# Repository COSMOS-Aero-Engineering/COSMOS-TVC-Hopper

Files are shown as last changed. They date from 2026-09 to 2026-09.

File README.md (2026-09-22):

# COSMOS — TVC 착륙 호퍼 + 강화학습

청도대원학교 항공우주공학 동아리 COSMOS의 26–27학년도 1학기 프로젝트.
단일 EDF 추력 + 배기 베인 4개로 자세를 제어하는 소형 VTOL 호퍼를 만들고,
전통 제어(PID/LQR)와 강화학습(RL) 제어를 정량 비교한다. SpaceX식 재사용 로켓의
역학을 안전한 축소 규모로 재현하는 게 목표.

## 시작점

- **[`AGENTS.md`](AGENTS.md)** — 정본 컨텍스트 문서: 설계 의도·확정 방향·현재 상태·문서 맵·다음 액션·안전 원칙. AI 세션이든 사람이든 기술적인 걸 파악하려면 이거 먼저. (`CLAUDE.md`는 이 파일로 가는 한 줄짜리 안내판)
- **[`docs/design/00-hopper-master-design.md`](docs/design/00-hopper-master-design.md)** — 마스터 설계도 (rev C)
- **[`docs/execution/TIMELINE.md`](docs/execution/TIMELINE.md)** — ⭐ **전체 타임라인 한 장** (간트차트로 한 것/남은 것/현재 병목). 진행 상황이 궁금하면 여기부터
- **[`docs/execution/week-01-kickoff.md`](docs/execution/week-01-kickoff.md)** — 1–2주차 실행 계획
- **[`docs/execution/member-weekly-tasks.md`](docs/execution/member-weekly-tasks.md)** — 부원 7명 개인별 주간 할 일

지금 당장 개발환경만 세팅하고 싶다면 바로 아래 "부원 퀵스타트"로.

---

## 부원 퀵스타트

처음 이 저장소를 받으면 아래에서 본인 팀 항목만 따라가면 된다. 두 팀 모두 제일 먼저 할 일은 같다.

```bash
git clone https://github.com/COSMOS-Aero-Engineering/COSMOS-TVC-Hopper.git
cd COSMOS-TVC-Hopper
git config user.name  "본인 이름"
git config user.email "본인 이메일"
```

### 소프트웨어팀

먼저 [uv](https://docs.astral.sh/uv/)를 한 번만 깔아둔다. 파이썬 버전과 패키지를 한꺼번에 맞춰주는
도구다 — 부원마다 파이썬 버전이 다른 문제까지 같이 없애준다.

```powershell
# Windows PowerShell
irm https://astral.sh/uv/install.ps1 | iex
```
```bash
# Mac / Linux
curl -LsSf https://astral.sh/uv/install.sh | sh
```

그다음은 어느 OS든 같다. (Mac은 **Apple Silicon만** 된다 — 고정된 torch 2.14.0에 Intel Mac용
휠이 없다. Intel Mac이면 Windows/Linux PC를 쓰거나, 부장에게 말해서 torch 버전을 조정한다.)

```bash
python tasks.py setup      # .venv 생성 + 고정 버전 의존성 설치 (torch 포함, 3~5분)
python tasks.py sanity     # 환경이 살아 있는지 확인
```

`환경 정상 동작 확인 완료`가 뜨면 끝. 안 뜨면 아래 [트러블슈팅](#트러블슈팅)부터 본다.

버전은 `uv.lock`에 고정돼 있다 — 손으로 `pip install` 하지 말 것. 부원마다 다른 버전이
깔리면 학습 결과가 서로 재현되지 않아, 문제가 생겼을 때 코드 탓인지 환경 탓인지 구분할 수 없다.
버전을 바꿔야 하면 `sim/pyproject.toml`을 고치고 `python tasks.py lock`을 돌린다(`uv.lock`과
`sim/requirements.txt`가 함께 갱신된다). 쓸 수 있는 명령 전체는 인자 없이 `python tasks.py`로 확인.

`python tasks.py check`는 한 번 통과한 검사를 건너뛴다 — 읽는 파일의 내용이 지난번과 같으면
다시 돌리지 않는다(약 39초 → 1초). 어떤 작업이 왜 건너뛰어지는지는 `python tasks.py graph`,
캐시를 무시하려면 `--force`, 아예 비우려면 `python tasks.py clean`.

환경을 다 갖췄으면 `hopper_aviary.py`를 열어보고, AI에게 이렇게 물어본다 — 그냥 읽고 넘어가지 말고 답을 **자기 말로 3문장**으로 줄여 팀 채팅방에 올릴 것. 서로 다르게 요약된 지점이 팀이 헷갈리는 지점이다.

```
이건 1인용 EDF 호퍼의 자세 제어를 학습시키는
강화학습 환경 코드야. 초보자에게 세 가지를 설명해줘.
1) observation이 무엇이고 왜 6개인지
2) action 5개가 각각 물리적으로 뭘 움직이는지
3) reward 식이 어떤 행동을 장려하고 어떤 걸 벌하는지
전문용어는 처음 나올 때 풀어서 써줘.
```

작업 폴더: `sim/`(RL 환경·학습 스크립트), `firmware/cosmos/`(Teensy 펌웨어 — **VSCode + PlatformIO 익스텐션** 필요, 펌웨어 담당만 설치하면 됨. 2026-09-19부터 Arduino IDE 대신 이걸 씀, `firmware/cosmos/README.md` 참고). 폴더마다 `platformio.ini`가 있는 독립 프로젝트라 `cd firmware/cosmos/imu_test && pio run -t upload`로 바로 업로드.

#### 확장 트랙 — 커넥톰 제약 정책망 (`sim/connectome/`)

초파리 커넥톰(실제 뇌 배선도)을 PPO 정책망의 **연결 구조**로 쓰는 비교군. 메인 트랙을
대체하지 않고 비교군을 하나 더 얹는 것이다. 설계 의도는
[`docs/design/connectome-control.md`](docs/design/connectome-control.md),
실행법은 [`sim/connectome/README.md`](sim/connectome/README.md).

```bash
python tasks.py connectome   # 그래프 생성 (합성 CX 링 어트랙터 + 셔플 대조군)
python tasks.py conncheck    # 제대로 도는지 확인
```

기존 `Kf=3.0e-8`은 추력이 실제의 약 1/37이라 어떤 제어기도 Stage 1을 풀 수 없는 값이었다.
PR #10에서 10 N 정적추력을 기준으로 역산한 **잠정값 `1.1e-6`**으로 보정해 비교 파이프라인은
다시 동작한다. 다만 실측값은 아니므로 결과를 최종 성능으로 해석하면 안 된다. 실험 A의 EDF
추력곡선이 나오면 다시 교체한다. 진단: `python sim/connectome/authority.py`.

### 엔지니어링팀

캘리퍼스로 잰 부품 실측값은 `cad/measurements.md`에 기록하고(없으면 새로 만들 것), CAD 파라미터(`cad/hopper_params.scad`)에 반영한 뒤 커밋한다. 배선 참고는 `docs/execution/bench-wiring.svg`.

작업 폴더: `cad/`(파라메트릭 CAD), `data/`(실험 로그 — 없으면 새로 만들 것).

핵심 배선 3갈래:

| 연결 | 비고 |
|---|---|
| Teensy ↔ BNO085 | **SPI 확정** — CS=10, MOSI=11, MISO=12, SCK=13, RST=20, INT=21, WAK/PS0=22, PS1=3.3V. 전부 3.3V 로직 |
| Teensy ↔ 수신기 | **레벨 시프터 필수** — 수신기 5V, Teensy 3.3V 전용 |
| Teensy → ESC | DShot 신호선 + 공통 접지. ESC의 BEC 5V는 Teensy에 물리지 않음 |

---

## 협업 규칙

정본은 [`AGENTS.md`](AGENTS.md)의 **"작업 규칙 — 브랜치·PR"**이다. 아래는 부원이 실제 작업할 때
따르는 절차다.

1. **한 작업 폴더에서는 한 번에 한 세션만 Git을 조작한다.** Claude·Codex·사람 터미널이 같은 폴더에서
   동시에 브랜치를 바꾸거나 커밋하면 서로의 작업 트리를 덮어쓸 수 있다. 다른 세션이 작업 중이면 먼저
   끝내거나 별도 worktree를 사용한다.
2. **항상 최신 `main`에서 새 브랜치를 만든다.** `main`에 직접 커밋·push하지 않는다. GitHub 룰셋도
   `main` 직접 변경을 막고 있으며, 모든 변경은 PR을 거쳐야 한다.
3. **PR에는 수동 리뷰어를 지정한다.** 리뷰 권한자는 부장 김민찬(`MINBBBB1201`)과 차장
   김준원(`junwonkim07`) 두 명뿐이다. CODEOWNERS는 자동 리뷰 알림이 너무 많이 생겨 삭제됐다(PR #12).
   작성자가 두 사람 외의 부원이면 둘 중 한 명을 직접 리뷰어로 지정한다.
4. **로컬 검사와 CI가 모두 통과해야 승인 대상이다.** PR 전에 `python tasks.py check`를 실행하고,
   GitHub의 sim 스모크 1개와 PlatformIO 펌웨어 빌드 2개가 모두 초록불인지 확인한다.
5. **리뷰와 머지 권한은 김민찬·김준원 두 사람에게만 있다.** 두 사람은 CI가 초록불인 것을 확인하고
   변경사항을 직접 검토한 뒤 본인이 올린 PR도 스스로 머지할 수 있다. 그 외 부원은 두 사람 중 한 명의
   승인(Approve)을 받아야 하며 직접 머지하지 않는다. 승인 뒤 새 커밋을 push했다면 다시 확인받는다.
6. **머지는 squash 방식만 쓴다.** 권한자가 `gh pr merge --squash --delete-branch`로 머지한다.
   미병합 브랜치는 GitHub 룰셋이 삭제를 제한하므로 임의로 지우지 않는다.
7. **충돌(conflict)이 뜨면 혼자 풀지 말고 부장에게 알린다.** 특히 다른 사람의 PR 브랜치에 직접
   커밋하거나 push하지 않는다.

추가 원칙:

- **남의 폴더는 건드리지 않는다.** 소프트웨어팀은 `sim/`·`firmware/cosmos/`, 엔지니어링팀은
  `cad/`·`data/`를 맡는다.
- PLACEHOLDER 값(예: `sim/params.yaml`의 추력 상수)을 실측값으로 바꿀 땐 커밋 메시지에 출처를 남긴다.
- AI 에이전트는 브랜치 생성·검사·PR 생성까지 진행할 수 있지만 머지 권한자는 아니다. **머지는 김민찬
  또는 김준원이 변경사항과 CI를 직접 확인한 뒤 실행한다.**

### 커밋 태그

커밋 메시지 앞에 대괄호 태그 하나를 붙인다.

| 태그 | 범위 | 예시 |
|---|---|---|
| `[cad]` | 기구 설계 | 상판 EDF 홀 실측값 반영 |
| `[fw]` | 펌웨어 | BNO085 쿼터니언 출력 추가 |
| `[sim]` | 시뮬 · RL | params.yaml 추력 상수 교체 |
| `[data]` | 실험 로그 | 9/19 실험 A 추력곡선 |
| `[docs]` | 문서 | README 트러블슈팅 추가 |

```bash
git switch main && git pull              # 항상 최신 main에서 시작
git switch -c sim/thrust-const-실측반영    # 브랜치부터 만든다
# ... 작업 ...
python tasks.py check                    # CI가 볼 걸 미리 확인
git add -A
git commit -m "[sim] params.yaml 추력 상수 실측값 반영"
git push -u origin HEAD
gh pr create --base main --reviewer junwonkim07
# gh가 없으면: push 후 터미널에 뜨는 링크를 열어 웹에서 PR 생성 → 우측 Reviewers에 junwonkim07
# 일반 부원은 CI 통과 + 김민찬 또는 김준원의 Approve를 기다린다.
```

브랜치 이름은 `<커밋 태그>/<짧은 설명>` 형태다. 예: `fw/imu-test-spi-mode`,
`docs/timeline-overview`. 머지와 원격 브랜치 삭제는 김민찬 또는 김준원이 처리한다.

---

## 트러블슈팅

이 섹션은 계속 채워나간다 — 새로 겪은 오류와 해결법은 발견한 사람이 바로 여기 추가하고 `[docs]` 태그로 커밋할 것.

| 증상 | 원인 | 해결 |
|---|---|---|
| `python`, `pip` 명령이 안 먹음 | 설치 시 PATH 미등록 | 파이썬 재설치 시 "Add python.exe to PATH" 체크. 이미 설치했다면 제어판에서 python 재설치(Modify) |
| `.venv\Scripts\activate` 실행 시 오류(실행 정책) | Windows 기본 PowerShell 스크립트 실행 제한 | PowerShell을 관리자로 열고 `Set-ExecutionPolicy RemoteSigned` 후 재시도, 또는 명령 프롬프트(cmd)에서 `.venv\Scripts\activate.bat` 사용. 애초에 활성화 없이 `python tasks.py <작업>`만 써도 된다 |
| `sanity_check.py` 실행 시 `ModuleNotFoundError` | 활성화가 안 된 상태로 직접 실행 | `python tasks.py sanity` 로 실행하면 uv가 알아서 맞춰준다. 직접 실행하려면 프롬프트 앞에 `(.venv)`가 보이는지 확인 |
| `git push` 시 로그인 창이 반복됨 | Git Credential Manager 인증 만료 | 뜨는 브라우저 창에서 GitHub 로그인 재시도. 안 뜨면 Settings → Developer settings → Personal access tokens에서 토큰 생성 후 비밀번호 칸에 붙여넣기 |
| Teensy 업로드 시 보드가 안 잡힘 | USB 드라이버 미인식 또는 프로그램 버튼 타이밍 | PlatformIO가 필요한 툴체인은 자동 설치하지만 Windows에서 드라이버가 안 잡히면 [PJRC Teensy Loader](https://www.pjrc.com/teensy/loader_win10.html) 드라이버만 별도 설치, 업로드 시작 직후 보드의 프로그램 버튼 눌러주기(버튼 손상 시 접점 순간 단락으로 대체 가능) |
| BNO085 값이 안 뜸 | SPI 배선 또는 PS0/PS1 모드 설정 문제 | CS=10, MOSI=11, MISO=12, SCK=13, RST=20, INT=21, WAK/PS0=22 확인. PS1은 3.3V에 묶고 전원도 3.3V만 사용. 모듈 실크가 다르면 `firmware/cosmos/imu_test/src/imu_test.ino` 상단 배선표와 실물 후면 표기를 대조 |
| `pip install` 중 `OSError: [Errno 2] No such file or directory: ...torch\include\...` | Windows 경로 길이 260자 제한 (torch는 경로가 아주 깊다) | 저장소를 더 짧은 경로로 옮기거나(예: `C:\dev\COSMOS-TVC-Hopper`), [긴 경로 지원 활성화](https://pip.pypa.io/warnings/enable-long-paths) |
| 설치 후 OneDrive가 몇 GB를 동기화하기 시작함 | `.venv`(torch 포함 ~1GB)가 OneDrive 폴더 안에 생겨서 | OneDrive 설정 → 백업/폴더 선택에서 `.venv` 제외. 지워도 `python tasks.py setup`으로 언제든 다시 만든다 |
| `uv: command not found` / `uv 이(가) 없다` | uv 미설치 또는 설치 후 터미널 미재시작 | 위 [소프트웨어팀](#소프트웨어팀) 설치 명령 실행 후 터미널을 새로 연다 |
| `환경을 uv.lock 에 맞추지 못했다` 또는 CI의 `uv sync --locked` 실패 | `pyproject.toml`만 고치고 `uv.lock`을 갱신하지 않음 | `python tasks.py lock` 후 `uv.lock`·`sim/requirements.txt`를 함께 커밋 |

## 구조

| 폴더 | 내용 |
|---|---|
| `docs/design/` | 설계도 · BOM · 리서치 · 참고 논문 |
| `docs/execution/` | 주차별 계획 · 조달 · 배선도 |
| `docs/presentation/` | 동아리 설명회 발표자료 |
| `firmware/` | 펌웨어 — `reference/SingleRotorUAV/`는 [SolidGeek/SingleRotorUAV](https://github.com/SolidGeek/SingleRotorUAV) (MIT) vendor-copy, `cosmos/`는 우리 코드 |
| `cad/` | 자체 파라메트릭 CAD (대안 — 주 경로는 SolidGeek Onshape 포크) |
| `kicad/` | Teensy·IMU·서보·RC·ESC 전원/신호 계통 스키매틱과 생성·검증 도구 |
| `sim/sim_stage1/` | 시뮬레이션 · RL — Stage 1 환경 + PPO 학습 1회 성공 완료 |
| `sim/connectome/` | 커넥톰 제약 정책망 (확장 트랙) — 초파리 배선을 정책망 구조로 |
| `data/` | 실험 로그 (CSV) |
| `tasks.py` | 작업 실행기 — 작업 순서와 입력 해시 캐시. 인자 없이 실행하면 목록 |
| `pyproject.toml` · `uv.lock` | 파이썬 워크스페이스 경계와 의존성 고정본 (`sim/pyproject.toml`이 sim 의존성 정본) |
| `.github/workflows/` | CI — PR마다 sim 환경/SB3 스모크 + PlatformIO 펌웨어 2종 빌드 자동 확인 |

## 라이선스 / 출처

`firmware/reference/SingleRotorUAV/`는 Emil Jacobsen (Aalborg University)의 MIT 라이선스 프로젝트를
그대로 포함한 것 — 해당 폴더의 `LICENSE`·`ORIGIN.md` 참고. 그 외 이 저장소의 내용은 COSMOS 동아리 작업물.

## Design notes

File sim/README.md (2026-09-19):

# sim/ — 시뮬레이션 · 강화학습

Stage 1 환경 구현 완료 (2026-09-14), PPO 1회 학습 성공. **더 이상 gym-pybullet-drones 안 씀** —
이유는 `AGENTS.md`의 "소프트웨어 스택" §2 참고(모터 1개+베인 4개 구조를 넣으려면 라이브러리 내부를
포크 수준으로 새로 써야 해서, 순수 `gymnasium.Env`를 직접 구현하는 쪽으로 결정).

> ⚠️ **여기 있는 Stage 1은 파이프라인 검증용 PoC다 — 최종 목표가 아니다.** numpy 직접적분이라
> 빠르고 의존성이 없지만 물리 신뢰도가 낮다(공력 lumped 근사, 서보 동특성 없음, 충돌 없음). 3D
> 물리엔진 기반 Stage 2로 넘어가는 계획(후보 비교·검증 상태 포함)은
> [`../docs/design/03-control-pipeline-design.md`](../docs/design/03-control-pipeline-design.md) §2가
> 정본. 이 Stage 1은 버리지 않고 앞으로도 빠른 스모크테스트용으로 계속 쓴다(§2 참고).

## 현재 있는 것 (`sim/sim_stage1/`)

| 파일 | 내용 |
|---|---|
| `hopper_aviary.py` | **`HopperAttitudeEnv`** — 위치 구속(만능조인트) 상태에서 자세만 제어하는 Stage 1 환경. 뉴턴-오일러 강체 회전방정식(자이로스코픽 교차항 포함) + ZYX 오일러각 운동학을 numpy로 직접 적분. `docs/design/references/`의 논문 3장(Modelling)을 그대로 코드화한 것 |
| `params.yaml` | 물리 상수. **CLalpha/CD0/Kf/mass/Jxx·Jyy·Jzz는 전부 PLACEHOLDER** — 실험 A(EDF 추력곡선) + 조립 후 실측 전까지는 의미 없는 값. `vane_arm_l/r`만 `cad/hopper_params.scad` 실측 기반이라 PLACEHOLDER 아님 |
| `sanity_check.py` | 환경이 안 깨졌는지 빠르게 확인(무작위 액션 20스텝) |
| `train.py` | PPO(stable-baselines3) 학습 스크립트 |
| `hopper_attitude_ppo.zip` | 학습된 모델 1회분 — PLACEHOLDER 물리값 기준이라 **성능 숫자 자체는 의미 없음**, 파이프라인이 도는지 확인용 |

## 관측 / 행동 (실제 구현 기준 — 이전 계획의 12/4차원 문서와 다름, 이게 현재 정답)

```
관측 obs (6): [phi, theta, psi, wx, wy, wz]   — 자세각(rad) + 바디 각속도(rad/s)
행동 act (5): [a1, a2, a3, a4, throttle]       — 베인 4개 각도(-1~1) + 스로틀(-1~1, 내부에서 0~1 변환)
과제: 초기 교란(±0.3rad)에서 수평(phi=theta=0)으로 복귀·유지
```

- 도메인 랜덤화: `params.yaml`의 `domain_rand` 블록 — Jxx/Jyy/Jzz ±30%, 베인 모멘트암 ±15%, Kf ±20%,
  무게중심-추력축 오프셋 ±3mm를 매 `reset()`마다 무작위 재추출.
- PLACEHOLDER 값을 실측치로 바꿀 때: **`params.yaml`만 교체, `hopper_aviary.py`는 안 건드림**
  (일부러 그렇게 분리해둔 것).

## 실행

저장소 루트에서 실행한다. 가상환경을 따로 활성화할 필요 없다 — uv가 `uv.lock`에 맞춰 알아서 맞춰준다.

```bash
python tasks.py sanity   # 환경 정상 동작 확인 (20스텝)
python tasks.py check    # CI와 같은 검사 — PR 올리기 전에
python tasks.py train    # PPO 학습 (200k 스텝)
```

처음이라면 `python tasks.py setup`을 한 번 먼저. 설치 방법은 루트 [`README.md`](../README.md)의 부원 퀵스타트.

## 다음 단계

- **실험 A(EDF 추력곡선) → `params.yaml`의 Kf·CLalpha·CD0 실측값 반영.**
- 조립 후 질량·관성 실측 → mass/Jxx/Jyy/Jzz 반영.
- Stage 2(전체 6DOF, 위치 자유) — 실험 A 데이터 확보 후 착수.
- baseline 제어(PID/LQR)가 실기에서 서기 전엔 이 학습 결과를 실기에 올리지 않음 (CLAUDE.md/AGENTS.md 원칙).

## 선행 (완료됨, 2026-09-13)

- `test_cartpole.py`, `test_pendulum.py`(레포 루트) — SB3 공식 퀵스타트로 워크플로 익히기. CartPole/Pendulum 둘 다 실행 성공.

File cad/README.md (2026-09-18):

# cad/ — 파라메트릭 CAD

CLAUDE.md/AGENTS.md 원칙: **프리핸드 CAD 금지.** 코드 기반 파라메트릭 설계 우선.

## 현재 정본

**[`hopper_params.scad`](hopper_params.scad)** — rev C 오픈 스탠드오프 프레임 전체를 담은 단일 파일.
EDF 실측(2026-09-13, 하우징 외경 72mm·볼트 플랜지 없음 확인) 반영해서 **분할 클램프(collar clamp)
마운트**로 설계됨(원래 볼트 마운트 가정이었던 게 실물과 안 맞아서 변경). 기둥-베인링 반경 불일치, 다리
스태거 미적용 등 구조 버그 2건도 수정된 상태.

- 맨 위 **"MEASURED"** 블록만 실측값. 나머지는 `docs/design/00-hopper-master-design.md` §4 값 그대로.
- 파일 맨 아래 `echo()`들이 조립 정합성을 콘솔에 출력 — 값 바꾼 뒤 OpenSCAD 콘솔에서 반드시 확인.
- `render_mode = "preview"` (조립 미리보기, 구매품인 탄소관·서보·배터리는 색블록으로만 표시) /
  `"print"` (실제 프린트 대상 파츠만) 두 모드. **`"print"`로 렌더해도 파츠 9개가 합쳐진 채로 나오니,
  외주용 STL은 모듈 하나씩 남기고 개별 export 필요** — 순서는 [`print_parts/README.md`](print_parts/README.md).

**2026-09-18: 실제로 렌더·export 완료.** 이 PC 바탕화면의 `openscad.exe`(2021.01, 정상 동작 — `Program
Files\OpenSCAD\`엔 껍데기만 남아있었던 게 원인이었음)로 렌더 확인. 검증 `echo()` 12개 전부 "정상" —
흡기 통로 안 막음, 베인이 제트 단면을 가로지름, 커플러가 캐비티 안에 들어감 등. 조립 미리보기 이미지는
[`renders/preview_colored.png`](renders/preview_colored.png)·[`renders/vane_ring_closeup.png`](renders/vane_ring_closeup.png).
9개 파츠 STL은 `print_parts/`에 실제로 있음(아래 "재사용 검토한 기존 STL" 밑 문단은 옛 상태 — 지금은
export 완료됨, `print_parts/README.md` 참고).

## 폴더

| 경로 | 내용 |
|---|---|
| `hopper_params.scad` | 정본 (위 설명) |
| `print_parts/` | 외주용 STL 7종을 여기다 export (아직 비어 있음 — OpenSCAD 로컬 미설치, `print_parts/README.md` 참고) |
| `print-orders/` | 실제로 외주에 발주 넣은 STL의 스냅샷(그때그때 폴더 만들어서). `.gitignore` 예외로 커밋됨 — 나머지 STL은 재생성 가능이라 커밋 안 함 |
| `legacy/` | rev B 단계에서 쓰던 3분할 스크립트(`params.scad`/`top_plate.scad`/`vane_ring.scad`) — **`hopper_params.scad`로 대체돼 더 이상 안 씀.** 과거 계산 참고용으로만 보존 |

## 워크플로

1. [OpenSCAD](https://openscad.org/downloads.html) 설치(무료). `hopper_params.scad` 열고 F5.
2. 부품 실측값이 바뀌면 파일 맨 위 `MEASURED` 블록만 수정 — 나머지는 자동 갱신.
3. 콘솔 `echo()` 출력으로 조립 정합성(클램프가 EDF 몸통 범위 안에 있는지, 트레이가 안 겹치는지 등) 확인.
4. 개별 모듈만 남기고 `F6`(Render) → STL export → `print_parts/`에 저장 (순서: [`print_parts/README.md`](print_parts/README.md)).
5. 슬라이서에서 확인(PETG, 인필 40%, 벽 4라인 — PLA 금지, 모터 폐열).
6. 실제 외주 발주 시 그 STL을 `print-orders/<날짜>/`로 복사해서 커밋.

## 재사용 검토한 기존 STL (참고 기록, rev C에선 안 씀)

- SolidGeek/SingleRotorUAV의 Onshape CAD — `firmware/reference/SingleRotorUAV/ORIGIN.md`·
  `docs/design/research-open-source-references.md` 참고. 펌웨어는 그쪽을 vendor-copy해서 쓰지만,
  CAD는 결국 이 저장소의 `hopper_params.scad`로 직접 구현하는 쪽으로 감(실측 기반 클램프 마운트가
  SolidGeek 원본 형상과 안 맞아서).
- K-9 TVC Hopper Test Vehicle(printables.com/model/164897) — 다리 배치 기하만 참고, 동체 재사용 안 함.

## 좌표 관례

- Z = 0: EDF 배기면(§4 기준면). +Z 위(흡기), −Z 아래(배기).
- 베인 0°(중립) = 시위가 Z축과 평행. 부호는 실기 TC-1에서 정합.

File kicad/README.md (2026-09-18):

# kicad/ — 회로도(스키매틱) 캡처

## 현재 상태 (2026-09-18)

**스키매틱 실제로 생성 완료** — `cosmos-avionics/cosmos-avionics.kicad_sch` + `.kicad_pro`.
`01-avionics-integration-final.md` §2.2(Teensy 핀맵)·§3(전원계통)을 그대로 넷리스트로 옮긴 것.
부품 20개, 넷 30개, 배선 83개 — 전부 스크립트로 생성(`_tools/gen_schematic.py`), 손으로 좌표를
찍은 게 하나도 없다(이 프로젝트의 "프리핸드 CAD 금지, 코드 기반 파라메트릭 우선" 원칙을 회로도에도
그대로 적용한 것).

**⚠️ 실제 KiCad ERC(오류검사)는 아직 못 돌렸다 — 이 PC의 환경 문제 때문**(아래 "알려진 문제" 참고).
대신 자체 구조 검증 스크립트(`_tools/validate_sch.py`)로 확인한 것: 괄호 균형 OK, 모든 `lib_id`가
`lib_symbols`에 실제로 선언돼 있음, UUID 중복 없음, 30개 넷 전부 연결점 2개 이상(끊어진 넷 없음).
**이건 "문법이 깨지지 않았다"는 확인이지 "회로가 맞다"는 확인이 아니다** — 진짜 ERC는 KiCad GUI로
열어서 돌려야 한다.

## 왜 KiCad를 쓰나

이 프로젝트는 PCB를 새로 설계하지 않는다 — 아비오닉스는 만능기판(perfboard) 수작업 배선이 정본
(`docs/design/01-avionics-integration-final.md` §5). **KiCad는 새 회로를 설계하는 도구가 아니라, 이미
확정된 핀맵·배선을 정식 회로도로 문서화하는 도구**로 쓴다.

- 조립 중 오배선을 조기에 발견하는 대조 도구(전자 탑재 시 스키매틱과 실물 대조).
- 발표·인수인계 자료 — 다음 학기 팀이 마크다운 표 대신 정식 회로도로 배선을 볼 수 있음.
- (스트레치) rev D에서 실제 커스텀 PCB로 갈 경우의 출발점.

## 열어보는 법

1. KiCad 10 설치(무료, [kicad.org](https://www.kicad.org/)) — 이미 이 PC엔 설치돼 있음
   (`%LOCALAPPDATA%\Programs\KiCad\10.0\`).
2. `cosmos-avionics/cosmos-avionics.kicad_pro`를 더블클릭 → KiCad가 열림 → Eeschema(회로도 편집기)
   아이콘 클릭.
3. **처음 열면 반드시 Inspect → Electrical Rules Checker(ERC) 실행** — 아직 아무도 실제로 돌려본 적이
   없다(아래 "알려진 문제" 때문에 이 세션에서 CLI로는 못 돌렸음). 여기서 나오는 오류·경고를 먼저 확인할 것.
4. 부품 20개가 격자로 나열돼 있음 — 예쁜 배치가 아니라 **넷 연결 확인용 1차 캡처**다. 팀에서 보기 좋게
   재배치해도 되고(같은 파일에 계속 편집), 그대로 둬도 넷 정보는 정확하다.

## 회로 구성 (`_tools/gen_schematic.py`에 넷리스트 그대로 있음)

Teensy 4.0·BNO085·MG90S 서보·FS-iA6B 수신기·ESC·UBEC·레벨시프터 전부 **공식 KiCad 심볼이 없어서**
`Connector_Generic:Conn_01xNN`(범용 핀헤더)로 대체 표시했다 — 각 부품의 `Value` 필드에 실제 정체를
적어뒀다(예: J6의 Value = "BNO085 IMU (CS,SCK,MOSI,MISO,INT,RST,WAK,PS1,VIN,GND)"). **핀 번호 자체는
의미 없고, 옆에 붙은 넷 이름(레이블)이 실제 신호다** — `01-avionics-integration-final.md` §2.2 표와
1:1 대조 가능.

| 부품 | 대응 |
|---|---|
| J1~J5 | Teensy 4.0의 기능별 핀 그룹(서보출력·RC입력·IMU SPI·DShot·전원) |
| J6 | BNO085 IMU |
| U1, U2 | 레벨시프터 #1(CH1,2) · #2(CH3,4,5) |
| J7 | FS-iA6B 수신기 |
| S1~S4 | MG90S 서보 ×4 |
| ESC1, M1 | ESC · EDF 모터 |
| U3, C1, C2 | UBEC · 캐패시터 2개 |
| SW1, BT1 | 킬스위치 · 4S LiPo |

## 알려진 문제 — kicad-cli가 이 PC에서 죽는다

`kicad-cli.exe`(그리고 아마 `kicad.exe`도 처음 실행 시)가 **`C:\Users\mimin\Documents\KiCad` 폴더를
못 만들어서 크래시**한다. 원인 확인함: **Windows Controlled Folder Access(랜섬웨어 방지)가 켜져 있고
(`Get-MpPreference`로 확인, `EnableControlledFolderAccess=1`), `Documents` 폴더를 보호 대상으로 잡고
있어서 kicad-cli를 포함한 모든 프로세스의 쓰기를 막고 있다.** 이건 보안 설정이라 AI가 직접 끄지 않았다.

**해결 방법 (둘 중 하나, 사람이 해야 함)**:
1. 가장 간단: **파일 탐색기로 `C:\Users\mimin\Documents\KiCad` 폴더를 직접 만든다** — 탐색기는 보통
   CFA 허용 목록에 있어서 이 한 폴더만 만들어두면 kicad-cli가 그 안에 쓰기만 하면 되니 넘어갈 수 있음
   (스크립트/터미널로는 이 폴더 생성 자체가 막혀서 이번 세션에서 못 했다 — 직접 테스트해봄, `mkdir`도
   `New-Item`도 전부 조용히 실패).
2. Windows 보안 → 바이러스 및 위협 방지 → 랜섬웨어 방지 → 폴더 액세스 제어에서 `kicad-cli.exe`·
   `kicad.exe`를 허용 목록에 추가(또는 일시적으로 기능 끄기).

이 중 하나를 하고 나면 `kicad-cli.exe sch erc kicad/cosmos-avionics/cosmos-avionics.kicad_sch` 로
진짜 ERC를 돌릴 수 있다 — 그때 결과를 이 문서에 반영할 것.

## 재생성 방법 (핀맵이 바뀌면)

`01-avionics-integration-final.md` §2.2·§3이 바뀌면, `_tools/gen_schematic.py`의 `COMPONENTS` 리스트만
고치고 다시 실행하면 된다 — 손으로 `.kicad_sch`를 고치지 않는다(파라메트릭 CAD와 같은 원칙).

```bash
cd kicad/_tools
python gen_schematic.py     # cosmos-avionics.kicad_sch 재생성
python validate_sch.py      # 구조 자체검증(문법/넷 연결)
```

`_tools/extract_symbols.py`는 KiCad 번들 심볼 라이브러리에서 실제 심볼 정의·핀 좌표를 그대로
추출하는 유틸 — 좌표를 손으로 베끼지 않으려고 만든 것(정확성 확보).

## 다음 단계

1. **Documents\KiCad 폴더 문제 해결 후 진짜 ERC 실행** — 위 "알려진 문제" 참고.
2. Eeschema에서 열어 보기 좋게 재배치(선택 — 넷 정보엔 영향 없음).
3. 실물 조립(전자 탑재, `semester-roadmap.md` Week 4~5) 때 이 스키매틱과 실제 배선 대조.
4. 커밋 태그: `[cad]` (전자 회로도도 기구·전자팀 소관, `README.md` 협업 규칙 참고).

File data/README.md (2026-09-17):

# data/ — 실험 로그 (아직 비어 있음)

시험 카드(TC-0~TC-7, `docs/design/00-hopper-master-design.md` §11)를 진행할 때마다 여기에 기록.
CSV 하나로 시작해도 됨 — 형식 강제 없음, 아래는 제안.

## 권장 파일명

```
data/YYYY-MM-DD_TC-<번호>_<한줄설명>.csv
예: data/2026-09-19_TC-0_throttle-only.csv
```

## 권장 컬럼 (실험 A류 — 추력 등)

```
timestamp, throttle_pct, thrust_g, current_A, voltage_V, notes
```

## 권장 컬럼 (실험 B/C류 — 자세·제어)

```
timestamp, roll_deg, pitch_deg, yaw_deg, gyro_p, gyro_q, gyro_r, servo1..4_pwm, motor_throttle, notes
```

`sim/sim_stage1/params.yaml`의 PLACEHOLDER 값(Jxx/Jyy/Jzz, CLα/CD0, Kf 등)을 실측값으로 바꿀 때,
그 실측이 나온 원본 로그를 여기 남겨두면 나중에 "이 숫자 어디서 나왔지" 추적 가능.

커밋 태그: `[data]`.

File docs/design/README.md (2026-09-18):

# docs/design/ — 설계 문서 색인

| 파일 | 내용 | 상태 |
|---|---|---|
| [`00-hopper-master-design.md`](00-hopper-master-design.md) | **마스터 설계도 (rev C).** 확정사항·아키텍처·치수·질량/추력 예산·서브시스템 상세·전자계통·펌웨어·RL 인터페이스·제작 순서·시험 카드·리스크 | rev C — 비행 컴퓨터를 Teensy 4.0(SolidGeek 오픈소스 포크)으로 교체, 기구/추진은 rev B 계승 |
| [`research-open-source-references.md`](research-open-source-references.md) | rev C 근거 리서치 — SolidGeek/SingleRotorUAV·Bresciani(PX4)·기타 검토 사례 비교, 채택 근거 | 완료 |
| [`general-arrangement.svg`](general-arrangement.svg) | 개략 배치도 (측면도 + 저면도, 치수) | rev B 형상 기준(기구 불변) |
| [`BOM-revC-teensy.md`](BOM-revC-teensy.md) | **구매 리스트(현행).** Teensy/BNO085/양방향DShot ESC 기준 | rev C |
| [`BOM.md`](BOM.md) | 구매 리스트(rev B) — 추진·베인·구조·구속·안전 항목은 **여전히 유효**, 비행컴퓨터 섹션만 rev C 문서로 대체됨 | 부분 supersede |
| [`modelling-notes-ch3.md`](modelling-notes-ch3.md) | 논문 3장(Modelling) 정리 — 운동방정식·베인 공력식, `sim/sim_stage1/hopper_aviary.py`와의 코드 대응표 | 2026-09-17 (재)작성 |
| `references/` | 원문 PDF(SolidGeek/Jacobsen 논문) | — |
| `../../firmware/reference/SingleRotorUAV/` | SolidGeek 펌웨어 vendor-copy(원본 그대로, 출처·라이선스는 `ORIGIN.md`) | — |
| `../../firmware/cosmos/` | 우리 팀이 실제로 고쳐 쓰는 펌웨어(위 vendor-copy 기반) | 착수 전 |
| `../../firmware/singlecopter.param.md` | ArduPilot SingleCopter 파라미터 — **rev C의 대안 경로**(§8.4) | 보존 |
| `../../cad/hopper_params.scad` | **CAD 정본.** EDF 실측(클램프 마운트) 반영, 구조버그 수정 완료. 자세한 워크플로는 `cad/README.md` | rev C, 2026-09-13 |
| [`01-avionics-integration-final.md`](01-avionics-integration-final.md) | **아비오닉스·배선·기계통합 확정판 (rev C.1).** Teensy 핀맵·전원계통·빵판/만능기판 배치·기계 통합·CG 재계산·조립순서·브링업절차 | rev C.1, 2026-09-17 |
| [`02-web-dashboard-design.md`](02-web-dashboard-design.md) | **웹 대시보드·3D 인터페이스 설계도(신규).** 소프트웨어팀 웹 산출물의 목표·아키텍처·CSV 데이터 계약·기술스택 | 신규, 2026-09-18 |
| [`03-control-pipeline-design.md`](03-control-pipeline-design.md) | **제어 파이프라인 심화 설계(신규).** PID/RL 아키텍처(직접비교 vs Residual RL)·3D 물리엔진 전환 로드맵(Stage 1 PoC→Stage 2)·State/Action Space·Domain Randomization 갭 분석·온보드 배포(ONNX/TFLite Micro)·참고 오픈소스 검증 | 신규, 2026-09-18 |
| [`avionics-breadboard.svg`](avionics-breadboard.svg) | **빵판 배치도** (Week 1 벤치 브링업용) — 홀 좌표·점퍼선까지 | rev C.1 |
| [`avionics-perfboard.svg`](avionics-perfboard.svg) | **만능기판 배치도 · 납땜 도면** (비행용) — 홀 좌표·장착홀 53.34×38.10 | rev C.1 |
| [`system-wiring-final.svg`](system-wiring-final.svg) | **전체 결선도**(비행 형상) — 전원 트리·핀맵·하네스 ID | rev C.1 |
| [`mechanical-integration.svg`](mechanical-integration.svg) | **기계 통합도** — 입면(z좌표)·평면(방위), 전자부품이 프린트 구조 어디에 붙는지 | rev C.1 |
| `tools/gen_board_svgs.py` · `tools/gen_system_svgs.py` | 위 도면 4장의 **생성기**. 치수가 바뀌면 스크립트만 고치고 재실행 (`python docs/design/tools/gen_*.py`) | — |
| `../../kicad/` | 아비오닉스 배선 스키매틱 캡처(신규 — 아직 비어있음, `kicad/README.md` 참고) | 착수 전, `semester-roadmap.md` Week 4 |
| `../../data/` | 실험 로그(CSV) | 착수 전 |

## 리비전

- **rev A** (70 mm EDF · 6S · Pixhawk · PVC 동체): 폐기.
- **rev B** (64 mm EDF · 4S · F405/ArduPilot · 오픈 스탠드오프 프레임): 기구·추진·질량예산·시험카드는 **rev C로 계승**.
- **rev C** (rev B 기구 + Teensy 4.0/SolidGeek 포크 + BNO085 + 양방향DShot + ESP32 + 자이로 정차 보정): **현행.**

## 읽는 순서

1. `research-open-source-references.md` — 왜 이 방향인지
2. 마스터 설계도 §0(확정)·§1(근거 요약)·§3(아키텍처)
3. 담당 서브시스템 §6, 특히 §6.5·§6.7·§8(rev C 변경 지점)
4. 구매: `BOM-revC-teensy.md` → 구매 순서대로
5. 제작: §10 → §14(아직 안 정한 것)
6. 시험: §11 — CLAUDE.md 안전 순서와 1:1

## 변경 규칙

- **형상 변경** = 팀 합의 + 마스터 설계도 개정(rev D…).
- **실측값 갱신** = `cad/params.scad`(또는 Onshape) `MEASURED` + 설계도 §4·§5. rev C.1, C.2…

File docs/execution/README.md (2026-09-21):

# docs/execution/ — 실행 (주차별 계획 · 조달 · 세션 운영)

| 파일 | 내용 |
|---|---|
| [`TIMELINE.md`](TIMELINE.md) | **⭐ 여기부터** — 간트차트로 한 장에 보는 전체 타임라인. 한 것/남은 것, 현재 병목 3개. 상세는 아래 문서들로 링크만 |
| [`week-01-kickoff.md`](week-01-kickoff.md) | **Week 1–2 마스터** — 타임라인, 부장이 준비할 모든 것, 필요 부품 전체 리스트, 금/토 세션 진행, 리더십 |
| [`semester-roadmap.md`](semester-roadmap.md) | **Week 3–10 마스터(신규)** — `week-01-kickoff.md`를 이어받는 세션별 실행계획. 팀 3개(기구·전자/소프트웨어/실험·운영)를 매주 세션 A(평일)·B(주말)로 배치, KiCad 착수 시점(Week 4)·baseline 확정(Week 7)·RL 비교(Week 8)·발표(Week 10) 포함 |
| [`member-weekly-tasks.md`](member-weekly-tasks.md) | **부원 7명 개인별 주간 태스크(신규)** — `week-01-kickoff.md`·`semester-roadmap.md`의 팀 단위 내용을 Week 1 잔여~Week 10까지 이름별로 배정. "이번 주 내가 뭘 하나"의 답 |
| [`procurement-review.md`](procurement-review.md) | 부장 구글시트 행별 검토 (✅ 맞음 / ⚠️ 확인필요 / ❌ 교체 / ➕ 추가) + 송수신기 추천 |
| [`bench-wiring.svg`](bench-wiring.svg) | 벤치 배선도 — Week 1 브링업(Teensy+IMU+ESC) → Week 2 확장(서보·수신기). **`01-avionics-integration-final.md` §4로 대체됨**(§12-7 참고), 구버전으로 남겨둠 |

## 지금 순서

1. `procurement-review.md`로 시트 확정 (⚠️ 링크 확인, B4를 FS-i6X 세트로)
2. `week-01-kickoff.md` §3 부품 전량 주문
3. `week-01-kickoff.md` §2 부장 준비 (특히 9/15 안전 계획 지도교사 서명)
4. 부품 도착 → §2-E 실측·프린트
5. 9/18–19 세션 → §4·§5

## 관련 (다른 폴더)

- 설계도·BOM·리서치: [`../design/`](../design/)
- SolidGeek 논문 PDF: [`../design/references/`](../design/references/)
- SolidGeek 펌웨어 원본: [`../../firmware/reference/SingleRotorUAV/`](../../firmware/reference/SingleRotorUAV/)

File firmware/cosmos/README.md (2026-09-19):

# firmware/cosmos/ — 우리 팀의 Teensy 펌웨어

`firmware/reference/SingleRotorUAV/`(SolidGeek 원본 vendor-copy, 손대지 않음)에서 필요한 드라이버를
그대로 복사해 쓰는 단위 테스트 스케치들 + (나중에) 전체 통합 펌웨어.

**2026-09-19: Arduino IDE → PlatformIO(VSCode) 전환 완료.** SW팀 개발환경이 오늘부로 PlatformIO
기준으로 바뀌었다 — 버전 고정(`platformio.ini`의 `lib_deps`), CI 연동 가능(`pio run`은 커맨드라인),
`sim/`(Python)과 같은 VSCode에서 작업 가능해서. 각 폴더가 이제 **독립된 PlatformIO 프로젝트**다
(`platformio.ini` + `src/`) — Arduino IDE의 "스케치 폴더 안 .h/.cpp만 같이 컴파일" 제약이 없어져서
드라이버 파일을 여러 폴더에 복사해둘 필요가 원래는 없지만, 지금은 vendor-copy 추적성 유지 목적으로
그대로 두고 있다(나중에 `lib/`로 통합 검토 가능).

## 현재 있는 것

| 폴더 | 내용 | 대응 실험 |
|---|---|---|
| `imu_test/` | BNO085 자세값(Roll/Pitch/Yaw) 시리얼 출력. `BNO080.h/.cpp`는 원본 vendor-copy에서 복사 | 실험 B(IMU 브링업) |
| `throttle_serial/` | 시리얼로 0~100 입력하면 그 %로 DShot 스로틀. `dshot.h/.cpp`는 원본에서 복사, 2초 무입력 시 자동 0% 페일세이프 포함 | 실험 C(DShot 모터제어), 실험 A(추력곡선)의 스로틀 소스 |

**둘 다 `pio run`으로 컴파일 검증 완료(2026-09-19)** — 이번에 처음 실제로 빌드해봤고,
`imu_test.ino`에서 진짜 버그를 하나 잡았다: `BNO080 imu;`가 인자 없는 생성자를 호출하는데
`BNO080.h`엔 4-인자 생성자(`CSPin,WAKPin,INTPin,RSTPin`, SPI용)만 있어서 **컴파일 자체가 안 됐다**
(Arduino IDE로도 마찬가지였을 것 — 이전엔 아무도 실제로 빌드해본 적이 없어서 몰랐던 것뿐).
`BNO080(255,255,255,255)`로 고침 — I2C(`.begin()`) 경로는 이 4개 인자를 안 쓰므로(생성자가
멤버변수에 저장만 함, `BNO080.cpp` 확인) 플레이스홀더로 안전. **여전히 Teensy 4.0 실물 업로드는 아직**
(컴파일 성공 ≠ 실물에서 동작 확인).

## 빌드·업로드 (PlatformIO)

```bash
cd firmware/cosmos/imu_test        # 또는 throttle_serial
pio run                            # 컴파일만
pio run -t upload                  # Teensy에 업로드
pio device monitor -b 115200       # 시리얼 모니터
```

VSCode PlatformIO 익스텐션 쓰면 왼쪽 개미 아이콘(PlatformIO 사이드바)에서 같은 동작을 버튼으로 — 이번에
SW팀이 오늘 설치한 그 익스텐션.

## 다음 단계

1. **`imu_test` 실물 업로드** → 축 방향·부호 확인(실험 B). 컴파일은 이미 통과했으니 이제 손에 있는
   Teensy에 `pio run -t upload`만 하면 됨.
2. `throttle_serial` — **반드시 EDF 팬 분리한 채로 먼저 확인**, 그다음 추력 스탠드에 고정해서 실험 A.
3. 통합 펌웨어(전체 제어 루프) 만들 때 이 두 스케치의 초기화·배선 코드를 재사용 — 가장 먼저 고칠 곳은
   `src/control.cpp`의 프로펄전 믹서(원본은 모터 2개 전제, 우리는 EDF 1개라 오히려 단순해짐).
4. 자이로 정차 보정 필요해지면(`docs/design/00-hopper-master-design.md` §6.7) `dshot.cpp`의 RPM
   텔레메트리 읽는 부분부터 확인.

커밋 태그: `[fw]`.

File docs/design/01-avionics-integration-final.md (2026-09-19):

# 아비오닉스 · 배선 · 기계 통합 — 최종 설계도 (rev C.1, 2026-09-17)

COSMOS PRJ-01. **이 문서가 "전자·배선·전자↔구조 결합"의 단일 진실 소스다.**
기구 형상(치수·질량예산·시험카드)의 정본은 여전히 [`00-hopper-master-design.md`](00-hopper-master-design.md) rev C이고,
이 문서는 그 §6.5(아비오닉스·배선)·§7(전자 계통)을 **실제로 만들 수 있는 수준까지 확정**한 것이다.
두 문서가 충돌하는 곳은 이 문서가 최신이다(충돌 지점은 §12에 전부 명시).

**초안이 아니라 확정판으로 쓰라고 만든 문서다.** 단, 아래 두 가지는 지금 물리적으로 확인이 불가능해서
"확정값 + 확인 절차" 형태로 적어뒀다 — 값을 다시 정하라는 뜻이 아니라, **첫 납땜/첫 프린트 전에 5분짜리
확인을 한 번 하라는 뜻**이다:

1. **CAD는 렌더 검증 완료** (2026-09-18). `C:\Program Files\OpenSCAD` 쪽엔 `openscad.exe`가 없지만
   **실행파일이 `C:\Users\mimin\Desktop\openscad.exe`(2021.01)에 따로 나와 있어** 그걸로 검증했다:
   `render_mode="print"` 전체 렌더 → **2-manifold 정상(Simple: yes), 독립 솔리드 17개**(= 프린트 파츠 수와 일치),
   `echo()` 정합성 검사 7건 전부 "정상". 검증 커맨드는 §9-0에 있다. 남은 건 **슬라이서에서의 최종 확인**뿐이다.
2. **부품 실물 치수 3건** — 만능기판 홀 개수, BNO085 모듈의 SPI 지원 여부(CS·PS0·PS1 패드), MG90S 이어 홀 간격.
   각각 §5.1·§2.4·§7.4에 "확인 포인트"로 박아뒀다.

---

## 0. 범위 · 전제

| 항목 | 이 문서에서 확정 | 근거 |
|---|---|---|
| Teensy 4.0 핀 할당 전체 | O — §2 | 펌웨어 소스 직접 확인 |
| 우리 포크에서 **반드시** 바꿔야 할 펌웨어 상수·로직 | O — §2.5 | 소스에서 충돌·안전 문제 발견 |
| 전원 트리 · 전류 예산 · 전선 규격 | O — §3 | BOM rev C |
| 빵판(브레드보드) 배치 — Week 1 벤치 | O — §4 | `bench-wiring.svg` 확장 |
| 만능기판(비행용) 배치 — 홀 좌표까지 | O — §5 | — |
| 하네스(전선 다발) 목록 · 길이 · 색 | O — §6 | — |
| 전자부품이 3D프린트 구조 **어디에 어떻게** 붙는지 | O — §7 | CAD 갱신 동반 |
| 질량·CG 재계산 및 트림 절차 | O — §8 | 마스터 §5.1 재계산 |
| 조립 순서 · 브링업 절차 | O — §9, §10 | TC-0 전 단계 |
| 베인 공력 형상·제어 게인·LQR 설계 | X — 범위 밖 | 마스터 §6.3·§8 |

**스테이지 전제**: 이 설계는 **STAGE 1(구속 자세 안정화)** 완결 기준이다. VL53L1X(고도)·PMW3901(광류)·
ESP32(WiFi)는 **핀만 비워두고 지금은 안 단다** — 비워둔 핀이 §2 표에 예약(RSV)으로 표시돼 있어
나중에 추가할 때 배선을 뜯을 필요가 없다.

---

## 1. 좌표계 · 방위 규약 (전 팀이 이 규약을 공유한다)

```
        +X = 0°   = "FWD"(전방)  - 베인 1 · 서보 1
        +Y = 90°  = "LEFT"(좌)   - 베인 2 · 서보 2
        -X = 180° = "AFT"(후방)  - 베인 3 · 서보 3
        -Y = 270° = "RIGHT"(우)  - 베인 4 · 서보 4
        +Z = 위(흡기 방향).  z = 0 은 EDF 배기면.
```

- **기둥·다리는 45°/135°/225°/315°** (베인과 45° 엇갈림 — 서보와 다리 뿌리가 안 부딪히게).
  기존 CAD는 다리를 0/90/180/270에 놨었다 = 베인·서보와 같은 방위 = 충돌. 이번에 수정(§12-3).
- **장비 선반(shelf) 2개**: 배터리 선반 = +Y쪽(45°·135° 기둥 사이), 아비오닉스 선반 = −Y쪽(225°·315° 기둥 사이).
- 롤 = X축 회전, 피치 = Y축 회전, 요 = Z축 회전. **부호 최종 정합은 실기 TC-1에서**
  (펌웨어 `write_servo()`의 부호로 맞춘다).
- 이 방위 라벨(FWD/LEFT/AFT/RIGHT)을 **기체·서보선·커넥터에 유성펜으로 실제로 써 붙인다.** 조립 후엔 구분 불가해진다.

---

## 2. Teensy 4.0 핀 할당 (확정)

### 2.1 원칙

- **Teensy 4.0의 표면 핀 0–23만 쓴다.** 24–39번은 보드 뒷면 SMD 패드라 학생 납땜 대상이 아니다.
- 스톡 SolidGeek 펌웨어의 핀 배치를 **최대한 그대로** 쓴다(코드 수정 최소화 = 버그 최소화).
- 나중에 붙일 센서(ToF·광류·ESP32)의 핀은 **지금 비워둔다.**

### 2.2 확정 핀맵

| 핀 | 용도 | 방향 | 연결 상대 | 스톡 코드 | 비고 |
|---|---|---|---|---|---|
| 0 | RSV (여유) | — | — | rc_pins[3]였음 | §2.4 폴백 때 RC CH1으로 씀 |
| 1 | **RC CH4 (요 스틱)** | IN | 수신기 CH4 ← 레벨시프터 | rc_pins[3] | 5V→3.3V 필수 |
| 2 | **서보 1 (FWD)** | OUT | MG90S #1 신호 | SERVO_1_PIN | 3.3V PWM |
| 3 | **서보 2 (LEFT)** | OUT | MG90S #2 신호 | SERVO_2_PIN | |
| 4 | **서보 3 (AFT)** | OUT | MG90S #3 신호 | SERVO_3_PIN | |
| 5 | **서보 4 (RIGHT)** | OUT | MG90S #4 신호 | SERVO_4_PIN | |
| 6 | RSV — 광류 CS (STAGE 3) | — | (PMW3901) | FLOW_CS_PIN | 비워둠 |
| 7 | **microSD CS** (선택, §3.5) | OUT | SD 브레이크아웃 CS | 미사용 | 안 쓰면 비워둠 |
| 8 | **DShot → ESC 신호** | OUT | ESC 신호선 | DSHOT_pin[0] | 유일한 모터 출력 |
| 9 | **RC CH5 (킬 스위치)** | IN | 수신기 CH5 ← 레벨시프터 | DSHOT_pin[1] | **`DShot motors(1)`로 바꿔야 비는 핀**(§2.5-1) |
| 10 | **IMU CS** | OUT | BNO085 CS | IMU_CS_PIN | SPI |
| 11 | **SPI MOSI** | OUT | BNO085 SI (+SD DI) | — | 공유 버스 |
| 12 | **SPI MISO** | IN | BNO085 SO (+SD DO) | — | 공유 버스 |
| 13 | **SPI SCK** | OUT | BNO085 SCK (+SD CLK) | — | 온보드 LED 겸용(정상) |
| 14 | RSV — ESP32 Serial3 TX | — | (ESP32 RX) | Serial3 | STAGE 2 |
| 15 | RSV — ESP32 Serial3 RX | — | (ESP32 TX) | Serial3 | STAGE 2 |
| 16 | RSV — ToF SCL1 (STAGE 3) | — | (VL53L1X) | Wire1 | 비워둠 |
| 17 | RSV — ToF SDA1 (STAGE 3) | — | (VL53L1X) | Wire1 | 비워둠 |
| 18 | **RC CH1 (스로틀)** | IN | 수신기 CH1 ← 레벨시프터 | rc_pins[0] | STAGE 1 필수 |
| 19 | **RC CH2 (롤 스틱)** | IN | 수신기 CH2 ← 레벨시프터 | rc_pins[1] | |
| 20 | **IMU RST** | OUT | BNO085 RST | IMU_RST_PIN | |
| 21 | **IMU INT** | IN | BNO085 INT | IMU_INT_PIN | |
| 22 | **IMU WAKE / PS0** | OUT | BNO085 WAK(PS0) | IMU_WAK_PIN | DShot 출력에서 뺐기 때문에 안전(§2.5-1) |
| 23 | **RC CH3 (피치 스틱)** | IN | 수신기 CH3 ← 레벨시프터 | rc_pins[2] | |
| 3V3 | 3.3V 출력(최대 250mA) | — | BNO085 VIN, 레벨시프터 LV | — | **서보 전원으로 절대 쓰지 말 것** |
| VIN | 5V 입력 | — | UBEC 5V (§3.4 조건부) | — | USB와 동시 사용 시 VUSB 패드 절단 필수 |
| GND | 접지 | — | 공통 GND 버스 | — | ESC GND와 반드시 연결 |

### 2.3 이 핀맵이 안전한 이유 (충돌 검증)

스톡 코드를 그대로 쓰면 **실제로 충돌이 난다.** 소스에서 확인한 것:

| 충돌 | 스톡 코드 | 해결 |
|---|---|---|
| **핀 22 이중 사용** | `DSHOT_pin[] = {8,9,22,23}` (`dshot.cpp:35`) vs `IMU_WAK_PIN 22` (`constants.h`) | 모터가 1개뿐이므로 `DShot motors(1)` → 출력 0번(핀 8)만 설정됨 → 9·22·23 해방 |
| 핀 23 이중 사용 | 위 + `rc_pins[]={18,19,23,1}` (`control.cpp:8`) | 동일 — DShot을 1출력으로 줄이면 23은 RC CH3 전용 |
| I2C(18·19) vs RC 입력 | RC가 18·19를 쓰는데 IMU를 I2C로 달면 충돌 | **IMU를 SPI로 간다**(스톡 `sensors.cpp`가 이미 `beginSPI()`). §2.4 |
| Wire1(16·17) vs 시리얼 | ToF가 Wire1=16/17을 씀 | RC를 시리얼(iBUS)로 안 받고 **PWM 5채널**로 받아서 회피 |

**그래서 수신기는 iBUS가 아니라 PWM 출력으로 쓴다.** FS-iA6B는 CH1~6 PWM 핀이 그대로 나와 있고,
스톡 코드가 이미 PWM 펄스폭을 인터럽트로 읽는 구조(`rc_input_isr0~3`)라 **라이브러리도 프로토콜 코드도 필요 없다.**
(`procurement-review.md`의 "PWM 출력 수신기가 오히려 편함" 판단과 일치.)

### 2.4 IMU는 SPI — 모듈 설정 (확인 포인트)

- BNO08x는 **PS1:PS0 = 1:1 일 때 SPI 모드**다. 중국 범용 BNO085 모듈은 대부분 PS0/PS1 패드가 노출돼 있다.
- 배선: `CS→10`, `SCK→13`, `SI(MOSI)→11`, `SO(MISO)→12`, `INT→21`, `RST→20`,
  `PS0→22`(스톡 코드가 WAKE로 토글하는 핀), `PS1→3V3`, `VIN→3V3`, `GND→GND`.
- **확인 포인트**: 산 모듈에 CS·PS0·PS1 패드가 없고 I2C 전용이면 → **폴백 플랜 B**:
  `sensors.cpp`의 `imu->beginSPI()`를 `imu->begin(0x4A, Wire, IMU_INT_PIN)`으로 바꾸고,
  **RC CH1·CH2를 핀 18·19에서 옮긴다**(추천: CH1→핀 0, CH2→핀 6).
  이 경우 `control.cpp:8`의 `rc_pins[]` 한 줄만 고치면 된다.
  폴백이 있으니 모듈이 어느 쪽이어도 프로젝트는 안 멈춘다 — 다만 **SPI 쪽이 코드 수정 0줄**이라 1순위다.

### 2.5 우리 포크(`firmware/cosmos/`)에서 **반드시** 바꿔야 하는 것

원본을 그대로 올리면 위험하거나 동작하지 않는다. 아래 5개는 **TC-0(첫 전원 인가) 전에 필수**다.

| # | 위치 | 원본 | 바꿀 것 | 이유 |
|---|---|---|---|---|
| **1** | `control.cpp:3` | `DShot motors(2);` | `DShot motors(1);` | 모터 1개. 안 바꾸면 핀 22(IMU WAKE)를 DShot이 뺏어가 **IMU가 죽는다** |
| **2** | `control.cpp:341-342` | `write_motor(DSHOT_PORT_1,…)` + `write_motor(DSHOT_PORT_2,…)` | PORT_1 한 줄만 | 포트 2는 존재하지 않음 |
| **3** | `control.cpp:init()` | `setConfig(DSHOT_PORT_2, …)` 2줄 | 삭제 | 동일 |
| **4** | `SingleRotorUAV.ino` setup() | `control.initiate_takeoff(0);` | **삭제** — CH5(킬)가 ARM 위치일 때만 아밍되게 | 부팅하자마자 FLYING 상태가 되는 건 학생 팀에게 위험 |
| **5** | `control.cpp: read_control_input()` | RC 펄스 타임아웃 없음 | **RC 워치독 추가**: 각 `rc_input[]`의 마지막 갱신 시각을 저장하고 200ms 이상 갱신이 없으면 `data.dshot = 0` + 서보 중립 | 지금 코드는 수신기가 죽어도 **마지막 펄스폭을 계속 유지**한다 = 폭주 |

권장(필수는 아님):

6. `MOTOR_MAX_DSHOT`를 TC-0 단계에선 600 이하로 낮춰두고, 추력곡선 확인 후 올린다.
7. `MOTOR_POLES 14` — 산 EDF 모터의 실제 극수로 확인(RPM 텔레메트리 쓸 때만 의미 있음).
8. CH5(핀 9)를 읽는 5번째 ISR 추가 — `rc_input_isr0~3`를 복사해 `isr4` 하나 더.

---

## 3. 전원 계통 (확정)

### 3.1 전원 트리

```
 4S LiPo 1300mAh 75C (14.8~16.8V)
   │  XT60
   ├─ [물리 킬스위치 >=80A, 인라인]   ← 배터리 (+) 경로. 상시 손 닿는 위치.
   │
   ├───────────► [470uF/35V 저ESR 캡] ─┬─► ESC (+)      … 메인 전류 최대 ~50A
   │              (ESC 입력단 20mm 내)  └─► ESC (−)
   │                                         └─3상─► EDF 모터
   │
   └───────────► UBEC 입력  →  5.5V 출력
                    ├─► 서보 전원 레일 (+5V) ─► MG90S x4
                    ├─► 수신기 FS-iA6B (+5V) ─► 레벨시프터 HV
                    └─► (선택) Teensy VIN   ← §3.4 조건 읽고 결정

 GND: 배터리(−) = ESC(−) = UBEC(−) = 만능기판 GND 버스 = Teensy GND = 수신기 GND … 전부 한 점(별 접지)
```

**ESC BEC는 쓰지 않는다.** 예산형 AM32/BLHeli_32 60A ESC는 BEC가 없는 제품이 많고, 있어도 UBEC와 병렬로
물리면 두 레귤레이터가 싸운다. **5V는 UBEC 단일 소스.** ESC에 BEC선이 있으면 잘라내거나 절연한다.

### 3.2 전류 예산

| 소비처 | 상시 | 피크 | 공급원 |
|---|---|---|---|
| EDF 모터 | 25~40 A (호버 추정) | ~50 A | 배터리 직결 |
| MG90S x4 | 4×0.1 = 0.4 A | 4×0.7 = **2.8 A** (전부 동시 스톨) | UBEC |
| FS-iA6B 수신기 | 0.08 A | 0.1 A | UBEC |
| Teensy + BNO085 + 레벨시프터 | 0.12 A | 0.15 A | USB 또는 UBEC |
| **UBEC 합계** | 0.6 A | **3.05 A** | UBEC 3A — **아슬아슬** |

→ **"5V 3A" 표기 제품의 실제 연속 정격이 2A인 경우가 흔하다. 5~6V / 3A 이상, 가능하면 5A짜리를 쓴다.**
서보 4개가 동시 스톨하는 건 베인이 뭔가에 걸렸을 때뿐이라 실사용은 1A 이하지만, 마진을 여기서 아끼지 않는다.
UBEC 출력단에 **470µF 이상 전해 캡**을 하나 더 달면 서보 돌입전류로 인한 5V 딥(→ 수신기 리셋)을 막는다.

### 3.3 전선 규격 (확정)

| 구간 | 규격 | 길이(목표) | 비고 |
|---|---|---|---|
| 배터리 ↔ 킬스위치 ↔ ESC (+/−) | **14 AWG 실리콘** | 각 130 mm | 50A 경로. 굵기 타협 금지 |
| ESC ↔ EDF 모터 3상 | ESC 기본선(보통 16AWG) | 70 mm | 3가닥을 **꼬아서** 배선(EMI 감소) |
| UBEC 입력 | 20 AWG | 100 mm | 배터리 XT60 병렬 탭 |
| UBEC 출력 → 5V 레일 | 20 AWG | 120 mm | |
| 서보 연장선 | 26 AWG 3선 | 각 **300 mm** | 링(z≈−36) → 선반(z≈150) 거리 ≈ 190mm + 여유 |
| 신호선(DShot·IMU·RC) | 26~28 AWG | 필요 길이 +20% | DShot선을 3상선과 **평행하게 묶지 말 것** |

### 3.4 Teensy 전원 — 이것만은 틀리면 보드가 죽는다

Teensy 4.0은 기본적으로 **USB 5V와 VIN이 내부에서 연결**돼 있다. USB를 꽂은 채 VIN에 UBEC 5V를 넣으면
두 전원이 맞붙는다(노트북 USB 포트까지 손상될 수 있다).

- **STAGE 1(구속 시험) 권장 = USB 급전.** 기체가 구속 스탠드에 매여 있으니 노트북 USB 케이블을 꽂아두고,
  **Teensy VIN에는 아무것도 연결하지 않는다.** 로깅도 USB 시리얼로 그대로 받는다(§3.5). 제일 단순하고 사고가 없다.
- 나중에 자립 급전이 필요해지면 → **Teensy 뒷면의 VUSB–VIN 패드 사이 트레이스를 커터로 절단**한 뒤
  UBEC 5V를 VIN에 연결한다. 되돌리기 번거로우니 STAGE 3 직전에 한다.
- 어느 경우든 **GND는 항상 공통**이다(USB 급전이어도 UBEC GND·ESC GND와 Teensy GND를 연결한다).

### 3.5 로깅 — Teensy 4.0에는 SD 슬롯이 **없다**

기존 문서 여러 곳에 "Teensy 자체 SD카드 로깅"이라 적혀 있는데, **SD 슬롯이 있는 건 Teensy 4.1이고 4.0에는 없다.**
확정 방침:

1. **STAGE 1 기본 = USB 시리얼 로깅.** `Serial.print()` CSV → 노트북에서 받아 저장.
   구속 시험이라 케이블이 문제되지 않는다. 파일명 규칙: `data/YYYYMMDD-TCx-런번호.csv`.
2. (선택) SPI microSD 브레이크아웃을 CS=핀 7로 붙일 수 있게 핀만 비워뒀다. 지금 살 필요 없음.
3. STAGE 2에서 ESP32(Serial3, 핀 14/15)로 WiFi 텔레메트리 — 스톡 `communication.cpp`가 이미 그 구조다.

---

## 4. 빵판(브레드보드) 배치 — Week 1 벤치용

**용도**: 실험 B(IMU 브링업)·실험 C(DShot 모터 제어)를 납땜 없이 하기 위한 임시 배선.
**비행/구속 시험에는 절대 쓰지 않는다**(§5.5). §5의 만능기판 배치가 **같은 핀·같은 순서**라
빵판에서 검증한 배선을 그대로 옮겨 납땜하면 된다 — 그러라고 좌표를 맞춰놨다.

### 4.1 보드 · 좌표 규약

- **하프사이즈 브레드보드(400핀, 약 83×55mm)** 1장. 열 1~30, 행 A~E(위 반)·F~J(아래 반), 양쪽에 ± 전원레일.
- **Teensy 4.0은 가운데 홈(0.3인치)을 걸치게 꽂는다** — 보드 폭이 0.6인치라 양쪽에 1홀씩 남는다(정상).
- 표기: `(열, 행)` — 예 `(5,F)` = 5열 F행.

### 4.2 부품 위치

| 부품 | 위치 | 방향 |
|---|---|---|
| Teensy 4.0 | 아랫줄 = **5~18열 F행**, 윗줄 = **5~18열 E행** | **USB 커넥터가 1열(왼쪽)을 향하게** |
| BNO085 모듈 | 21~26열 F~J행 | 모듈 1번 핀이 21열 |
| 레벨시프터 #1 (4ch) | 21~26열 A~E행 | HV쪽이 위(+레일 쪽) |
| 수신기 FS-iA6B | 빵판 밖 — 점퍼 3선으로 연결 | |
| ESC | 빵판 밖 — 신호선 1 + GND 1만 빵판으로 | |

**Teensy 핀 ↔ 열 대응** (위 방향으로 꽂았을 때)

| 열 | 5 | 6 | 7 | 8 | 9 | 10 | 11 | 12 | 13 | 14 | 15 | 16 | 17 | 18 |
|---|---|---|---|---|---|---|---|---|---|---|---|---|---|---|
| **F행(아랫줄)** | GND | 0 | 1 | 2 | 3 | 4 | 5 | 6 | 7 | **8** | **9** | **10** | 11 | 12 |
| **E행(윗줄)** | VIN | GND | 3V3 | **23** | **22** | **21** | **20** | 19 | 18 | 17 | 16 | 15 | 14 | 13 |

> Teensy는 **핀 12와 13이 USB 반대쪽 끝에 나란히** 오는 게 정상 — 꽂고 나서 이게 맞는지 보면 방향이 맞는지 바로 안다.

### 4.3 점퍼 목록 (이 순서대로 꽂는다)

**(a) 전원 레일 먼저**

| # | 부터 | 까지 | 색 |
|---|---|---|---|
| J1 | Teensy 3V3 `(7,E)` | 위쪽 **+레일** | 빨강 |
| J2 | Teensy GND `(5,F)` | 아래쪽 **−레일** | 검정 |
| J3 | 위쪽 −레일 | 아래쪽 −레일 | 검정 (GND 한 점) |

**(b) IMU (SPI) — 실험 B**

| # | Teensy 핀 (빵판 좌표) | BNO085 | 색 |
|---|---|---|---|
| J4 | +레일 (3.3V) | VIN | 빨강 |
| J5 | −레일 | GND | 검정 |
| J6 | 핀 10 `(16,F)` | CS | 노랑 |
| J7 | 핀 13 `(18,E)` | SCK | 파랑 |
| J8 | 핀 11 `(17,F)` | SI / MOSI | 초록 |
| J9 | 핀 12 `(18,F)` | SO / MISO | 흰색 |
| J10 | 핀 20 `(11,E)` | RST | 회색 |
| J11 | 핀 21 `(10,E)` | INT | 보라 |
| J12 | 핀 22 `(9,E)` | WAK / PS0 | 갈색 |
| J13 | +레일 (3.3V) | PS1 | 빨강 (SPI 모드 고정) |

**(c) ESC (DShot) — 실험 C**

| # | 부터 | 까지 | 색 |
|---|---|---|---|
| J14 | 핀 8 `(14,F)` | ESC 신호선 | 주황 |
| J15 | −레일 | ESC GND선 | 검정 — **이거 없으면 DShot이 안 나간다** |

> ESC의 전원(굵은 빨강/검정)은 **빵판에 절대 꽂지 않는다.** 빵판 접점은 1~2A가 한계다.
> ESC 전원은 배터리 → 킬스위치 → ESC로 직접 간다.

**(d) 수신기 (레벨시프터 경유) — Week 1 후반~Week 2**

| # | 부터 | 까지 | 색 |
|---|---|---|---|
| J16 | UBEC +5V | 레벨시프터 **HV** + 수신기 (+) | 빨강 |
| J17 | +레일 (3.3V) | 레벨시프터 **LV** | 빨강 |
| J18 | −레일 | 레벨시프터 GND + 수신기 (−) | 검정 |
| J19 | 수신기 CH1 신호 | 시프터 HV1 → LV1 → 핀 18 `(13,E)` | 주황 |
| J20 | 수신기 CH5 신호 | 시프터 HV2 → LV2 → 핀 9 `(15,F)` | 주황 |

**(e) 서보 (Week 2, 동작 확인만)**

- 서보 신호 4선 → 핀 2·3·4·5 = `(8,F)`·`(9,F)`·`(10,F)`·`(11,F)`
- 서보 (+)는 **UBEC 5V에서 직접** (빵판 레일 경유 금지 — 돌입전류로 접점이 탄다)
- 서보 (−)는 공통 GND

### 4.4 빵판 단계 안전 규칙

1. 모터가 달린 EDF는 **반드시 추력 스탠드에 볼트로 고정**된 상태에서만 전원을 넣는다.
2. 빵판에 4S(16.8V)가 들어가는 배선은 **하나도 없다.** 빵판 최고 전압은 5V.
3. 배선을 바꿀 땐 **항상 배터리를 물리적으로 분리**한 뒤(킬스위치만 믿지 않는다).
4. 첫 전원 인가 순서: ① USB로 Teensy만 → 시리얼 확인 → ② UBEC/수신기 → ③ 마지막에 배터리 메인.

---

## 5. 만능기판(비행용 보드) 배치 — 확정

빵판에서 §4를 통과했으면 **같은 연결을 만능기판에 납땜**한다. 구속 시험·비행은 이 보드로만 한다.

### 5.1 보드 · 좌표 규약

- **5×7cm 양면 만능기판(2.54mm 피치)** 1장. 보통 **가로 24홀 × 세로 18홀**.
  **확인 포인트**: 산 보드의 실제 홀 수를 세서 다르면 아래 좌표를 ±1 이동(설계 의도는 "가장자리에서 2홀 안쪽").
- 좌표: 왼쪽아래 홀 = `C1R1`, 오른쪽으로 C 증가(C1~C24), 위로 R 증가(R1~R18). 피치 2.54mm.
- **장착 구멍 4개**: `C2R2`·`C23R2`·`C2R17`·`C23R17` 격자홀을 **Ø3.2mm로 드릴 확공**.
  → 구멍 중심 간격 = **53.34 × 38.10 mm**. 이 값이 §7.3 아비오닉스 선반의 인서트 위치와 **1:1로 일치**한다.

### 5.2 배치 (보드를 위에서 본 그림, 왼쪽이 USB)

```
 R18 ┌───────────── +5V 버스 (맨 윗줄, 주석선) ─────────────┐
 R17 │ o장착홀                                      o장착홀 │
 R16 │  [470uF 캡]            [  BNO085 IMU 모듈  ]         │
 R15 │                        [  (6핀 소켓, 수평)  ]         │
 R14 │                                                      │
 R13 │  ┌──────── Teensy 4.0 (암핀헤더 소켓) ────────┐       │
 R12 │  │ 윗줄 : VIN G 3V3 23 22 21 20 19 18 17 16 15 14 13 │
  …  │  │                                            │      │
 R6  │  │ 아랫줄: GND 0 1 2 3 4 5 6 7 8 9 10 11 12   │      │
 R5  │  └────────────────────────────────────────────┘      │
 R4  │  [레벨시프터 4ch #1]   [레벨시프터 4ch #2]            │
 R3  │  [서보 3핀 헤더 x4]    [RC 3핀 헤더 x5]    [ESC 2핀]  │
 R2  │ o장착홀                                      o장착홀 │
 R1  └───────────── GND 버스 (맨 아랫줄, 주석선) ───────────┘
      C1                                                  C24
```

### 5.3 홀 좌표 확정표

| 부품 | 점유 홀 | 비고 |
|---|---|---|
| **Teensy 아랫줄 소켓**(14핀 암헤더) | **C5R6 ~ C18R6** | C5=GND, C6=핀0 … C18=핀12 |
| **Teensy 윗줄 소켓**(14핀 암헤더) | **C5R12 ~ C18R12** | C5=VIN, C6=GND, C7=3V3, C8=핀23 … C18=핀13 |
| GND 버스 (Ø0.8 주석도금 단선) | **C1R1 ~ C24R1** | 별 접지의 중심 |
| +5V 버스 | **C1R18 ~ C24R18** | UBEC에서 급전 |
| +3.3V 버스 (짧게) | **C1R17 ~ C8R17** | Teensy 3V3(C7R12)에서 분기 |
| BNO085 6핀 소켓 | **C15R15 ~ C20R15** | 모듈이 **수평으로 눕도록** (IMU 축 정렬, §7.5) |
| 레벨시프터 #1 (RC CH1·CH2) | **C3R4 ~ C8R4** (HV/LV 2줄이면 R3·R4) | |
| 레벨시프터 #2 (RC CH3·CH4·CH5) | **C11R4 ~ C16R4** | |
| 서보 3핀 헤더 x4 (S1~S4) | R3에 3홀씩: **C1~C3 / C4~C6 / C7~C9 / C10~C12** | 신호–5V–GND 순서 고정 |
| RC 입력 3핀 헤더 x5 | R3에 3홀씩: **C14~C16** 부터 순서대로 | CH1,2,3,4,5 |
| ESC 2핀 헤더 (신호·GND) | **C22R3, C23R3** | |
| 470µF 캡 (5V 레일 안정화) | **C2R15 / C4R15** | 극성 주의 |

### 5.4 납땜 순서 (이 순서가 제일 덜 고생한다)

1. 장착홀 4개 Ø3.2 확공 → **납땜 전에** 스탠드오프로 선반에 한 번 올려보고 맞는지 확인.
2. GND 버스(R1)·+5V 버스(R18) 주석선 먼저 — 나중에 하면 부품에 막힌다.
3. Teensy 암헤더 2줄(R6·R12). **Teensy를 꽂아 정렬을 확인한 뒤** 납땜(휘면 못 뺀다).
4. 3핀 헤더류(R3) → 레벨시프터(R4) → IMU 소켓(R15) → 캡.
5. 배선(0.4~0.5mm 에나멜선/UEW): §2.2 핀맵대로, **한 줄 연결할 때마다 표에 체크**.
6. 전원 없이 **멀티미터 도통 확인**: ① 5V↔GND 단락 없음 ② 3V3↔GND 단락 없음 ③ 각 신호핀이 목적지까지 도통.
7. Teensy 빼고 5V만 인가 → 레일 전압 확인 → 끄고 Teensy 장착.

### 5.5 왜 빵판이 아니라 만능기판인가 (이 결정은 안 바꾼다)

EDF 스로틀 구간의 진동에서 빵판 접점은 **간헐적으로 떨어진다.** IMU 신호선 하나가 순간 끊기면 자세 추정이 튀고
그게 그대로 서보·모터 출력이 된다 — 구속 상태라도 위험하고, 무엇보다 **PID vs RL 비교 데이터가 오염**돼
프로젝트의 결론 자체를 못 쓰게 된다. 빵판은 벤치 브링업 전용.

---

## 6. 하네스(배선 다발) 목록

각 다발은 **양 끝에 같은 라벨**을 붙인다(마스킹테이프 + 유성펜). 조립 후엔 색만으로 구분 못 한다.

| ID | 구간 | 가닥 | 규격 | 길이 | 커넥터 | 비고 |
|---|---|---|---|---|---|---|
| **H1** | 배터리 → 킬스위치 → ESC | 2 | 14AWG | 130+130 mm | XT60 | 470µF 캡을 ESC단에 |
| **H2** | ESC → EDF 모터 | 3 | ESC 기본선 | 70 mm | 3.5mm 불릿 | 3가닥 꼬기. 상 순서는 TC-0에서 회전방향 보고 결정 |
| **H3** | ESC → 보드(신호·GND) | 2 | 26AWG | 150 mm | 2핀 듀퐁 | 3상선과 **분리 경로** |
| **H4** | 배터리 탭 → UBEC | 2 | 20AWG | 100 mm | XT60 병렬 | |
| **H5** | UBEC → 보드 +5V/GND | 2 | 20AWG | 120 mm | 2핀 | |
| **H6~H9** | 보드 → 서보 S1~S4 | 3×4 | 26AWG | **300 mm** | 3핀 듀퐁(JR 순서) | 기둥 225°·315°로 내려감 |
| **H10** | 수신기 → 보드 | 신호 5 + 전원 2 | 26AWG | 200 mm | 3핀 ×5 | CH1,2,3,4,5 |
| **H11** | Teensy → 노트북 | — | micro-USB | 2 m | — | 구속 시험 중 상시 연결(로깅) |
| (예약) H12 | 보드 → ESP32 | 4 | 26AWG | 150 mm | — | STAGE 2 |

**배선 경로 원칙** (마스터 §6.5 "전부 기류 밖"의 구체화)

- 모든 전선은 **반경 r ≥ 40mm 밖**으로만 지난다(흡기 기류관 Ø78 안으로 절대 들어가지 않게).
- 배기 제트(하향, 반경 36mm)와 베인 작동 범위(베인링 ID 76) 안으로는 **아무것도 지나지 않는다.**
- 서보선 4다발은 **225°·315° 기둥을 따라** 2다발씩 나선형 케이블랩으로 감아 내린다.
- 3상선(H2)·메인전원(H1)은 **270° 쪽**, 신호선은 **225°/315° 쪽** — 고전류와 신호를 물리적으로 분리.
- 모든 다발은 20~30mm마다 케이블타이(선반·기둥의 타이슬롯 사용).
- 커넥터는 **당겨서 안 빠지는지 손으로 확인**하고, 흔들리는 건 열수축으로 고정.

---

## 7. 기계 통합 — 전자부품이 프린트 구조 어디에 어떻게 붙나

### 7.0 왜 기존 CAD의 "트레이"를 버렸나 (중요)

기존 `hopper_params.scad`의 `avionics_tray_plate()`·`battery_tray_plate()`는 z=125·z=95에서 **원점 중심**의
평판이었다. 이 위치는:

1. **EDF 흡기 통로 한가운데다.** 상판(z=178)의 Ø78 흡기홀과 EDF 흡입구 립(z=92) 사이 = 공기가 지나는 길.
   여기에 111×40mm 판을 가로로 놓으면 흡기를 정면으로 막는다 → 추력 손실·소음·실속.
2. **기둥과 물리적으로 겹친다.** 판 반길이 55.5mm > 기둥 위치 33.9mm라 기둥 4개를 관통한다.
3. 어디에도 **고정되지 않는다** — 붙일 구조가 없는 떠 있는 판이었다.

→ **확정 대안: 흡기관 바깥의 "장비 선반(equipment shelf)" 2개.** 기둥 사이에 수평으로 걸치고, 흡기
스트림튜브(반경 39mm)보다 바깥(r ≥ 42)에만 존재한다. 높이는 상판 바로 아래 — CG를 최대한 높이려는
마스터 §5.3 원칙과도 맞는다.

### 7.1 장비 선반 — 공통 사양

| 항목 | 값 |
|---|---|
| 재질 | PETG, 벽 4라인, 인필 40% (마스터 §10-4와 동일) |
| 두께 | 3 mm (+ 가장자리 리브 5mm) |
| 부착 | 양 끝의 **Ø6.4 반원 새들(saddle)** 2개가 기둥(Ø6 CF튜브)을 감싸고 **케이블타이 2개씩**으로 조임. 접촉면에 얇은 고무/EVA 시트 |
| 높이 조절 | 타이 방식이라 **기둥을 따라 상하 슬라이드 가능 = 종 CG 트림 수단**(§8.3) |
| 기둥 간 거리 | 인접 기둥 2개 사이 = 2 × 48 × sin45° = **67.88 mm** (새들 중심 간 거리) |
| 안쪽 경계 | 내측 가장자리 반경 **r ≥ 42 mm** (흡기 스트림튜브 Ø78 + 여유 3mm) |
| 상면 높이 | **z = +150 mm** (배기면 기준). 상판 하면(z=178)까지 28mm, EDF 립(z=92)에서 58mm 위 |

### 7.2 배터리 선반 (+Y측, 45°·135° 기둥 사이)

| 항목 | 값 |
|---|---|
| 판 크기 | **CAD 현행(`equip_shelf_battery()`) 기준 70 × 80 mm**(반경 방향 70·접선 방향 80) — 아래 배터리 실측 반영해 이 절 갱신함, 이전 판(112×46) 표기는 구버전 |
| 배터리 실측 | **63.5 × 32.5 × 15 mm(가로×세로×두께), 2026-09-19 최종 측정(3축 전부)** — `cad/measurements.md` 참고. 9/18 1차값(34×74, 높이 미측정)은 재측정으로 대체됨 |
| 스트랩 슬롯 | 3 × 16 mm 슬롯 4개(양쪽 2쌍) → 벨크로 스트랩 2개로 X자 고정 |
| 반경 방향 조절 | 새들 쪽 **±8mm 장공** — 팩을 안팎으로 밀어 횡 CG 트림 |
| 턱(lip) | 아래쪽으로 4mm 턱 — 스트랩이 느슨해져도 팩이 미끄러지지 않게 |
| 배터리 방향 | 긴 변(63.5mm)이 **접선 방향**(판 폭 80mm 안에 8mm씩 여유), 짧은 변(32.5mm)이 반경 방향(판 반경길이 70mm 안에 여유 큼). 두께 15mm는 선반 위 높이만 차지 — 상판 하면까지 28mm라 여유 충분. 케이블은 −Y(ESC 방향)를 향하게 |

### 7.3 아비오닉스 선반 (−Y측, 225°·315° 기둥 사이)

| 항목 | 값 |
|---|---|
| 판 크기 | 84 × 60 mm |
| **만능기판 장착** | M3 열융착 인서트 4개, 중심 간격 **53.34 × 38.10 mm**(= §5.1 보드 구멍) → M3×10 나일론 스탠드오프 → 보드 |
| 보드 방향 | **수평(눕힘).** 보드 위 IMU 축이 기체 축과 그대로 일치한다 — 세워 달면 펌웨어에서 축을 90° 돌려야 해서 실수가 난다 |
| 수신기 자리 | 보드 옆 30×20 영역 + 타이슬롯 2개. 안테나 2개는 **서로 90°**로, 기둥에 테이프 고정(전원선과 30mm 이상 이격) |
| UBEC | 선반 **하면**에 케이블타이 2개(타이슬롯 2쌍) |
| 배선 통로 | 내측 가장자리에 15×6 슬롯 2개 — 서보선·3상선이 아래로 빠지는 길 |

### 7.4 서보 · 베인 (베인링에 붙는 부분)

| 항목 | 값 |
|---|---|
| 서보 위치 | 베인링 **바깥면**, 0°/90°/180°/270°(= 베인과 같은 방위) |
| 구동 방식 | **직결(direct drive)** — 서보 스플라인이 베인 피벗축(반경 방향)과 **동축**. 푸시로드·벨크랭크 없음 |
| 왜 직결인가 | 링키지 유격(백래시)이 곧 베인 각도 오차 → RL 정책이 시뮬에서 배운 각도와 실제 각도가 달라진다(sim-to-real 오차의 최대 원인). 직결이면 명령각 = 실제각(서보 자체 유격만). 부품 수도 줄어든다 |
| 폴백 | 반경 방향 공간이 부족하면 BOM C4(피아노선)+C5(혼) 푸시로드 방식. **이 경우 링키지 비를 측정해 `sim/sim_stage1/params.yaml`에 반영해야 한다** |
| 서보 보스 | 베인링 바깥면에 두께 4mm 판으로 일체 프린트, 폭은 이어 위치를 전부 덮도록 파라메트릭으로 자동 조정됨(비대칭 배치 대응, 아래 참고). 이어 홀 2개(M2 셀프탭)는 **출력축 기준** −3 / +30mm 위치(`servo_ear_to_shaft`=3mm, `servo_ear_pitch`=33mm — 둘 다 2026-09-19 SG90 실물 캘리퍼스 실측 확정). 몸통 두께(`servo_body_w`)도 23mm로 실측 확정(조사자료 12.0~12.4보다 훨씬 큼). **홀이 출력축 기준 비대칭**(조사자료 가정은 대칭에 가까웠음)이라 마운트판 폭 계산 로직 자체를 "양쪽 홀을 전부 덮는 최소폭" 방식으로 수정(`servo_boss_solid()` 참고) — 안 고쳤으면 먼 쪽 홀이 판 밖으로 나갈 뻔했음. `servo_body_l`(몸통 긴변)·`coupler_horn_t/w`는 아직 미측정 — 실물 서보 도착 시 재대조 |
| 스파 | Ø3 CF 로드. 링 안쪽(r≈20)에서 서보 장착판(r=64)까지 관통 — 보어 Ø3.2. **재단 길이 60mm**(r=4~64). 링 벽(r=38~48) 구간에 **황동 부싱**(BOM C3) |
| 하드스톱 | **베인링 벽에 낸 창(슬롯)이 스톱 역할** — 베인 바깥 끝이 링 벽 안으로 3mm 물려 들어가 있고, 슬롯 폭·높이가 ±15°에서 딱 닿게 계산돼 있다(CAD `vane_slot_w`/`vane_slot_h`). 서보가 죽어도 베인이 배기를 완전히 막지 못한다 |
| 베인 본체 | 프린트, 반경 **r=4~41**(링 ID 38보다 3mm 더 물림), 시위 25mm(z방향), 두께 2.5mm. 피벗선을 따라 Ø6.6 중앙 스파인으로 부풀려 Ø3.2 보어를 감쌈(2.5mm 판에 그냥 뚫으면 두 동강 난다) |
| 스플라인 ↔ 스파 연결 | **해결됨(CAD rev C.1)** — 서보 장착판을 링 바깥면에서 16mm 띄우고(`servo_standoff`, 커플러 길이 14mm가 들어가야 해서 12→16으로 키움), 그 캐비티 안에 **서보 혼(알루미늄 싱글암, BOM C5) + 프린트 커플러(`vane_coupler`, Ø14×14)** 를 넣어 Ø3 스파와 잇는다. 커플러는 4개 프린트(+예비 2개 권장). **확인 포인트**: 혼 암의 두께·폭을 실측해 `coupler_horn_t`(2.2) / `coupler_horn_w`(9.0)를 고칠 것 |

### 7.5 IMU(BNO085) 장착 — 제어 성능이 여기서 갈린다

1. **위치**: 아비오닉스 만능기판 위(선반 = 강체). 기체 중심축에서 약 65mm 떨어져 있다 —
   **자세(자이로·쿼터니언)에는 영향 없음**(각속도는 위치와 무관). 단 STAGE 3에서 가속도 기반 위치추정을 켤 땐
   이 레버암(≈65mm)을 코드에 반영해야 한다 → `params.yaml`과 `sensors.cpp`에 주석으로 남길 것.
2. **축 정렬**: 모듈 X축을 기체 +X(FWD, 0°)와 일치. 보드를 눕혀 달기 때문에 Z축은 자동으로 맞는다.
   모듈 실크의 축 화살표 방향을 **선반에 유성펜으로 그려둔다.**
3. **진동 절연**: 모듈 밑에 1mm 양면 폼테이프(3M VHB급) — 고주파는 줄이고 저주파 자세는 그대로 전달.
   **말랑한 스펀지 금지**(저주파에서 IMU가 따로 흔들려 자세 추정이 망가진다).
4. **간섭 회피**: 3상선·메인전원에서 **30mm 이상** 이격(마스터 §7). 자력계를 안 쓰므로 자기간섭 영향은
   제한적이지만 거리는 확보한다.

### 7.6 ESC 장착

| 항목 | 값 |
|---|---|
| 위치 | **270°(−Y) 방향, 아비오닉스 선반 하면에서 내려오는 브래킷**, z ≈ 110~145, r ≈ 45 |
| 이유 | ① 흡입구(z=92)로 빨려드는 공기가 지나는 자리라 **실제로 냉각된다** ② 모터까지 70mm ③ 횡 질량균형에 유리(§8.2) |
| 고정 | 케이블타이 2개 + 폼테이프. 방열면(라벨 반대쪽)이 **바깥을 향하게** |
| 캡 | 470µF/35V 저ESR을 ESC 전원 입력 **20mm 이내**에 납땜, 극성 확인, 열수축 |
| 금지 | ESC를 배터리 선반 위에 올리지 말 것(LiPo에 열을 준다) |

### 7.7 전체 배치 요약 (z 좌표)

| z (mm) | 무엇이 있나 |
|---|---|
| +182 / +178 | 상판 윗면 / 아랫면 (Ø78 흡기홀) |
| **+150 ~ +175** | **장비 선반 2개** — 배터리(+Y) / 만능기판+Teensy+IMU+수신기(−Y) |
| +110 ~ +145 | ESC 브래킷 (270°) |
| +92 | EDF 흡입구 립 |
| +70 | EDF 클램프(기존 CAD 그대로) |
| 0 | **EDF 배기면 = 기준면** |
| −22 ~ −50 | 베인링 (상단 −22 / 하단 −50) |
| **−36** | **베인 피벗축 = 서보 회전축** (링 수직 중앙 — 마스터 §4의 "배기면→피벗 22mm"는 실제로는 링 *상단*까지의 거리였다, §12-9) |
| −140 | 발 바닥 |

---

## 8. 질량 · CG 재계산 (마스터 §5.1 갱신)

### 8.1 AUW 재계산 — 기존 문서의 합계가 틀렸다

마스터 §5.1 표의 항목을 그대로 더하면 **709 g**인데 합계가 **660 g**으로 적혀 있다(약 50g 누락, §12-1).
여기에 이번에 추가된 선반·브래킷을 더하면:

| 항목 | g |
|---|---|
| 마스터 §5.1 항목의 실제 합 | 709 |
| 장비 선반 2개 + ESC 브래킷 (PETG) | +25 |
| **AUW (확정 추정)** | **≈ 735 g** |

→ **TWR = 1300 / 735 ≈ 1.77.** 구속 시험 기준(≥1.15)·저고도 홉 기준(≥1.6) **모두 충족**. 결론은 안 바뀐다.
(850mAh 배터리를 쓰면 −50g → 685g, TWR 1.90.)

### 8.2 좌우(횡) 질량 균형

| 쪽 | 부품 | 질량(g) | 반경 r(mm) | 모멘트(g·mm) |
|---|---|---|---|---|
| **+Y** | 배터리 팩 | 150 | 59 | 8850 |
| −Y | 만능기판+Teensy+IMU+헤더 | 60 | 65 | 3900 |
| −Y | 수신기 | 10 | 65 | 650 |
| −Y | UBEC + 배선뭉치 | 15 | 60 | 900 |
| −Y | ESC + 캡 | 45 | 45 | 2025 |
| | **−Y 합** | | | **7475** |
| | **잔차** | | | **1375 → 횡 CG 오프셋 ≈ 1.9 mm** |

목표: **횡 CG 오프셋 ≤ 3mm.** 이 배치는 설계상 이미 만족한다. 실제 값은 §8.3으로 측정해 확인한다.

### 8.3 CG 측정 · 트림 절차 (조립 후 필수, 30분)

1. 배터리 포함 완전체를 **가는 끈으로 상단 베일에 매달아** 정지시킨다 → 추력축이 연직이면 횡 CG ≈ 0.
   기울면 기운 쪽이 무겁다.
2. 트림 순서: ① 배터리 선반의 **반경 장공**으로 팩을 ±8mm 이동 → ② 남으면 배선 다발 위치 조정 →
   ③ 마지막 수단으로 반대쪽에 5g 이내 밸런스 웨이트.
3. **종(수직) CG**: 기체를 옆으로 눕혀 칼날/봉 위에서 균형점을 찾고 배기면(z=0)에서의 거리를 잰다.
   **선반을 기둥 위로 슬라이드**하면 CG가 올라간다(타이 풀고 5mm씩).
4. 측정값을 `data/mass-cg-YYYYMMDD.md`에 기록하고 **`sim/sim_stage1/params.yaml`에 반영**.

### 8.4 CG 목표치 정정 — 마스터 §4의 "140~180mm"는 도달 불가

이번 배치로 종 CG를 계산하면 **배기면 위 약 68 mm**다. 배터리를 더 올려도(선반이 이미 상판 바로 아래)
70mm대가 한계다. EDF 본체 160g이 z≈46에 고정돼 있고 베인링·다리·서보(195g)가 음수 z에 있기 때문에
**140mm는 물리적으로 불가능**하다(140mm를 만들려면 질량 대부분이 z>200에 있어야 하는데 거긴 흡기 통로다).

→ **확정 목표를 "배기면 위 60~75 mm"로 정정한다.** 실질적으로 중요한 건 절대 높이가 아니라
**베인까지의 모멘트암 = z_cg − z_vane ≈ 68 + 36 = 104 mm**이고(피벗이 −36, §12-9), 이 값이 제어 권한(베인각 → 토크)을 결정한다.
`sim/sim_stage1/params.yaml`의 베인 모멘트암도 이 값으로 맞춰야 시뮬과 실기가 일치한다.
"CG는 높을수록 좋다"는 원칙 자체는 유지 — 그래서 선반을 상판 바로 아래에 붙인 것이다.

---

## 9. 조립 순서 (체크리스트)

**9-0. 프린트 전** (CAD 렌더·manifold 검증은 2026-09-18에 끝남 — 아래는 재확인용)
☐ `"C:\Users\mimin\Desktop\openscad.exe" -o out.stl -D 'render_mode="print"' cad/hopper_params.scad`
   → `Simple: yes` / `Volumes: 18`(= 솔리드 17 + 바깥공간) / `echo()` 7건 "정상" 확인
☐ 파츠별 STL export(`cad/print_parts/README.md`) ☐ 슬라이서에서 치수·서포트 확인(PETG)

**9-1. 프린트**
☐ 상판 ☐ 베인링(서보 보스·스파 보어·하드스톱 슬롯 포함) ☐ 베인 ×4 ☐ EDF 클램프
☐ **배터리 선반** ☐ **아비오닉스 선반** ☐ **ESC 브래킷** ☐ **스파 커플러 ×4** ☐ 발범퍼 ×4
→ 총 **프린트 파츠 17개** (렌더에서 독립 솔리드 17개로 확인됨)

**9-2. 후가공**
☐ M3 열융착 인서트 4개(아비오닉스 선반) ☐ 만능기판 장착홀 Ø3.2 확공 ☐ 부싱 압입 ☐ 서포트 제거·구멍 리머

**9-3. 전자(벤치, 기체에 안 올린 상태)**
☐ Teensy 핀헤더 납땜 ☐ **빵판 배선(§4)** ☐ 실험 B(IMU) 통과 ☐ 실험 C(DShot) 통과
☐ 만능기판 납땜(§5.4) ☐ 도통 검사 ☐ 빵판과 동일 동작 재확인

**9-4. 기구 조립**
☐ 베인링에 서보 4개 ☐ 베인+스파 삽입, ±15° 스톱 확인 ☐ 손으로 돌려 걸림 없음
☐ 기둥 4개(45° 계열) ☐ 상판 ☐ EDF 클램프 장착·유격 0 ☐ 다리 4개(기둥과 동일 방위) ☐ 베일

**9-5. 전자 탑재**
☐ 선반 2개를 기둥에 새들+타이로(z=150) ☐ 만능기판 스탠드오프 장착 ☐ IMU 축 방향 확인·표시
☐ ESC 브래킷 ☐ 하네스 H1~H10(§6) ☐ 라벨 부착 ☐ 모든 다발 타이 고정
☐ **흡기·배기 통로에 아무것도 없는지 눈으로 확인**

**9-6. 계측**
☐ 질량 측정 ☐ 횡 CG ≤3mm ☐ 종 CG 기록 ☐ `params.yaml` 갱신

**9-7. 전원 인가 전 최종**
☐ 킬스위치 OFF ☐ 5V↔GND 단락 없음 ☐ 배터리 극성 ☐ 팬 경로에 손·공구 없음
☐ 그릴 장착 ☐ 보안경 ☐ 소화기 위치 확인 ☐ **지도교사 서명된 안전계획서**

---

## 10. 브링업(첫 전원) 절차 — 이 순서를 지킨다

| 단계 | 하는 일 | 합격 기준 | 실패 시 |
|---|---|---|---|
| **P1** | Teensy만 USB 연결 | 시리얼에 "Initializing…" → "Ready" | 보드 인식·Teensyduino 확인 |
| **P2** | IMU 출력 확인(기체 정지) | 롤·피치 ±0.5° 이내 안정, 손으로 기울이면 부호 일치 | SPI 배선·PS0/PS1 확인(§2.4) |
| **P3** | 수신기 + UBEC ON (**배터리 메인은 아직 OFF**) | 5채널 펄스폭 1000~2000µs 정상, **킬 스위치 내리면 스로틀 0 처리** | 레벨시프터·GND 확인 |
| **P4** | 서보 4개 동작(모터 없이) | 명령각 ↔ 실제 베인 방향 일치(TC-1 부호 정합), 스톨음·발열 없음 | 혼 각도 재장착, 부호 반전 |
| **P5** | **EDF를 추력 스탠드에 볼트 고정한 상태에서** 배터리 연결 | ESC 아밍음 정상, 스로틀 0에서 무회전 | 즉시 킬 |
| **P6** | 스로틀 10% 5초 | 이상음·진동·연기 없음, 배기가 아래로 나감 | 3상 중 2선 교체 |
| **P7** | 10%씩 증가(실험 A 추력곡선) | 각 점에서 추력·전류 기록 | 온도·전류 초과 시 중단 |
| **P8** | 기체에 장착 후 구속 스탠드(M1)에서 TC-0 | 마스터 §11 시험카드대로 | — |

**모든 단계에서**: 손은 킬스위치에, 사람은 배기 축선 밖에, 배터리는 30초 이상 연속 방전 금지
(STAGE 1은 짧게 여러 번).

---

## 11. 고장 모드 · 대응 (전자 계통)

| 증상 | 가장 흔한 원인 | 확인 / 대응 |
|---|---|---|
| ESC가 삐 소리만 내고 안 돎 | Teensy↔ESC **GND 미연결** | H3의 GND선 확인. DShot은 공통 GND 없으면 절대 안 된다 |
| IMU 인식 실패 | SPI 모드 미설정(PS0/PS1) / CS 배선 | §2.4. 그래도 안 되면 폴백 I2C |
| IMU 값이 튄다(스파이크) | 폼테이프 없이 직결, 또는 전원선 근접 | §7.5-3,4 |
| 서보가 떨린다(지터) | Teensy 3.3V 신호 레벨 부족 / 5V 레일 딥 | UBEC 출력 캡 추가 → 안 되면 74HCT125 버퍼 |
| 수신기가 리셋된다 | 서보 돌입전류로 5V 딥 | UBEC 용량 상향(§3.2) |
| 스로틀이 안 먹거나 폭주 | 자동 아밍 / RC 워치독 없음 | **§2.5-4, §2.5-5 반드시 적용** |
| 롤 명령에 피치가 같이 움직임 | 자이로스코픽 정차 커플링 | 마스터 §6.7 · TC-2.5 |
| 비행 중 간헐 리셋 | 진동으로 커넥터 접촉 불량 | 빵판 사용 금지(§5.5), 커넥터 열수축 고정 |

---

## 12. 이번 설계에서 발견한 기존 문서·CAD 문제 (전부 처리함)

| # | 문제 | 어디 | 처리 |
|---|---|---|---|
| **1** | 질량 합계 오류 — 항목 합은 709g인데 합계가 660g | 마스터 §5.1 | §8.1에서 정정(AUW≈735g, TWR 1.77). 결론 불변 |
| **2** | CG 목표 140~180mm가 물리적으로 도달 불가 | 마스터 §4·§5.3 | §8.4에서 60~75mm로 정정 + 근거 계산 |
| **3** | 다리 방위가 베인·서보와 겹침(둘 다 0/90/180/270) | `hopper_params.scad` `legs()` | CAD에서 다리를 45° 계열로 수정(기둥과 동일 방위 = 하중 경로도 개선) |
| **4** | 트레이 2개가 흡기 통로 한가운데 + 기둥 관통 + 고정 수단 없음 | `hopper_params.scad` | §7.0 — 장비 선반 2개로 대체(CAD 반영) |
| **5** | 베인이 배기 제트(r≤36) 바깥(r=48)에 그려져 있어 **기류에 닿지 않음** | `hopper_params.scad` `vanes()` | CAD에서 반경 방향 평판(r=4~38, 시위 25 z방향)으로 수정 |
| **6** | "Teensy SD카드 로깅" — Teensy 4.0에는 SD 슬롯 없음(4.1과 혼동) | `BOM-revC-teensy.md` B3, `week-01-kickoff.md` | §3.5 — USB 시리얼 로깅 확정, SD는 선택(핀 7 예약) |
| **7** | 배선도엔 "BNO085 = I2C"인데 펌웨어는 SPI, 게다가 I2C 핀(18/19)은 RC가 씀 | `bench-wiring.svg` | §2.4 — SPI 확정 + 폴백 명시. 벤치 배선은 이 문서 §4로 대체 |
| **8** | 스톡 펌웨어 핀 충돌(22·23) · 부팅 자동 아밍 · RC 워치독 없음 | `firmware/reference/` | §2.3·§2.5 — 포크 시 필수 수정 5건 목록화 |
| **9** | 마스터 §4의 "EDF 배기면 → 베인 피벗축 22mm"는 실제로는 **링 상단까지의 거리**였다. 링 높이 28의 중앙이 피벗이므로 실제 피벗은 **−36mm** | 마스터 §4 · `hopper_params.scad` | CAD rev C.1에서 `vane_pivot_z = 링 중앙`으로 정의. 이 문서 §7.7·§8.4의 모멘트암(104mm)도 그 값 기준으로 정정 |
| **10** | 서보 스플라인 ↔ Ø3 스파를 잇는 부품이 없었음(축 방향 여유 0) | `hopper_params.scad` | CAD rev C.1에서 해결 — 장착판을 16mm 띄운 캐비티 + `vane_coupler()` 프린트 파트 4개. §7.4 참고 |
| **11** | 서보 마운트판 폭 계산이 이어 홀이 출력축 기준 대칭이라고 가정하고 있었다. 실측(`servo_ear_to_shaft`=3, `servo_ear_pitch`=33)으로 −3/+30 비대칭 배치가 확인되면서, 안 고쳤으면 먼 쪽 이어 홀이 판 밖으로 뚫려 나갈 뻔했다 | `hopper_params.scad` `servo_boss_solid()` | 2026-09-19 — 폭 계산을 "양쪽 홀 중 더 먼 거리 기준"으로 수정, 렌더 재검증(17개 매니폴드 유지) 완료. §7.4 참고 |

---

## 13. 아직 부장이 정해야 하는 것 (이 3개뿐)

1. **UBEC 용량** — 3A vs 5A. (권장: 5A. 차액 ¥10 수준이고 §3.2의 유일한 마진 부족 지점)
2. **microSD 로깅 추가 여부** — STAGE 1은 USB로 충분. 자립 급전 갈 때 결정(핀 7은 이미 비워둠).
3. **남은 서보 실측 2개 + 커플러 실측** — `servo_ear_pitch`(33)·`servo_ear_to_shaft`(3)·`servo_body_h`(28)·
   `servo_body_w`(23)는 SG90 실물로 확정됨(§7.4, §12-11). 아직 안 잰 건 `servo_body_l`(몸통 긴변)과
   `coupler_horn_t`/`coupler_horn_w`(MG90S 혼 두께·폭) 3개뿐. 이거 재서 CAD에 넣고,
   **베인링(4시간짜리)을 뽑기 전에 서보 장착판만 시험 프린트해서 맞는지 확인**할 것.
   (직결이 물리적으로 불가한 경우에만 BOM C4·C5 푸시로드로 폴백)

---

## 14. 관련 도면 (이 문서와 같이 본다)

| 도면 | 내용 |
|---|---|
| [`avionics-breadboard.svg`](avionics-breadboard.svg) | §4 빵판 배치 — 홀 좌표·점퍼선 색까지 그대로 |
| [`avionics-perfboard.svg`](avionics-perfboard.svg) | §5 만능기판 배치 — 납땜 도면 |
| [`system-wiring-final.svg`](system-wiring-final.svg) | §2·§3·§6 전체 결선도(비행 형상) |
| [`mechanical-integration.svg`](mechanical-integration.svg) | §7 기계 통합 — 입면(z좌표)·평면(방위) |
| [`tools/gen_board_svgs.py`](tools/gen_board_svgs.py) · [`tools/gen_system_svgs.py`](tools/gen_system_svgs.py) | 위 도면 4장의 **생성기**. 좌표·치수가 바뀌면 스크립트만 고치고 `python docs/design/tools/gen_*.py` 재실행 — 문서 표와 도면이 따로 놀지 않게 하기 위한 장치 |
| [`general-arrangement.svg`](general-arrangement.svg) | 기존 기체 개략 배치도 |
| [`../execution/bench-wiring.svg`](../execution/bench-wiring.svg) | 구버전 벤치 배선도 — §12-7 때문에 이 문서 §4로 대체됨 |

---
*rev C.1 — 아비오닉스·배선·기계통합 확정. 다음 갱신은 ① 실측(서보 이어간격·만능기판 홀수·BNO085 SPI 지원)
반영 ② TC-1 부호 정합 결과 ③ 실제 CG 측정값 반영 시점.*

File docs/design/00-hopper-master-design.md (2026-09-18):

# 착륙 호퍼 — 마스터 설계도 (rev C, 2026-09-05)

COSMOS PRJ-01. 이 문서가 기체의 **단일 진실 소스(single source of truth)**다.

## 리비전 이력

| rev | 골격 | 상태 |
|---|---|---|
| A | 70 mm EDF · 6S · Pixhawk · PVC 플리넘 동체 · AUW ~1.6 kg · ₩620k–1.36M | **폐기** — 제작 전, 비용·엔지니어링 부담으로 스케일 다운 |
| B | 64 mm EDF · 4S · F405(ArduPilot) · 오픈 스탠드오프 프레임 · AUW ~0.65 kg · ₩260–420k | **부분 계승** — 추진·구조·치수·질량예산·시험카드는 그대로 rev C로 이어짐. **FC/센서/펌웨어 베이스만 교체됨** |
| **C** | **rev B와 동일한 기체 + 추진, 단 비행 컴퓨터를 Teensy 4.0(SolidGeek/SingleRotorUAV 오픈소스 포크) + BNO085 + 양방향 DShot ESC + ESP32로 교체. 자이로스코픽 정차 보정(Bresciani/PX4) 포함** | **현행** |

> **rev C의 의도**: 딥 리서치([`research-open-source-references.md`](research-open-source-references.md)) 결과,
> 우리와 **거의 동일한 목적·구조**를 가진 기체가 이미 완전한 CAD + 펌웨어 + 89쪽 이론 문서로 공개돼 있다는
> 걸 확인했다(Aalborg University 석사논문, Emil Jacobsen, MIT 라이선스). 이걸 기구·펌웨어의 새 출발점으로
> 삼아 **엔지니어링(기구·전자·저수준 제어) 시간을 최소화**하고, 남는 시간을 소프트웨어(시뮬레이션·RL)에 쓴다.
> 여기에 PX4 코어 개발자 Mathieu Bresciani가 단일 EDF 드론에서 실제로 겪고 해결한 **자이로스코픽 정차
> 커플링** 문제의 해법(로터 RPM 기반 보정)도 같이 이식한다.
> CLAUDE.md 상위 골격(EDF·핀 방식·RL 2단계 로드맵)은 그대로. CLAUDE.md가 처음부터 "저예산 대안"으로
> 열어둔 **Arduino/Teensy 경로**를, 처음부터 직접 짜는 대신 검증된 오픈소스로 실현하는 것 — **이탈이 아니다.**

**부록 자료**: 이 문서 + 관련 리서치·논문 PDF·CAD 링크·펌웨어 원본을 [§16](#16-첨부-자료-모음)에 전부 모아뒀다.

---

## 0. 확정 사항 (Locked)

| # | 항목 | 확정 | 근거 |
|---|---|---|---|
| L1 | 추진 | **64 mm EDF, 4S, 11~12블레이드**, 하향 배기. 정적 추력 1.3~1.45 kgf | rev B 그대로. SolidGeek 논문도 "실전엔 단일 EDF가 더 나은 선택"이라 사후 결론 — 교차검증됨 |
| L2 | 자세제어 | 배기류 속 **제어핀(베인) 4개**, 서보 구동, 짐벌 없음 | CLAUDE.md 핀 방식. SolidGeek·Bresciani 둘 다 동일 방식 |
| L3 | **비행 컴퓨터** | **Teensy 4.0** + **BNO085** IMU + **양방향 DShot(RPM 텔레메트리) 지원 ESC** + **ESP32**(WiFi 텔레메트리). [SolidGeek/SingleRotorUAV](https://github.com/SolidGeek/SingleRotorUAV) 펌웨어를 포크해 프로펄전만 단일 EDF로 수정 | **rev C 핵심 변경.** CLAUDE.md의 "Teensy 대안"을 처음부터 안 짜고 검증된 오픈소스로 실현. ArduPilot/F405 경로는 §8.4에 대안으로 보존 |
| L4 | 구조 | **오픈 스탠드오프 프레임** — 상판(EDF) + 4개 기둥(CF/알루) + 하부 베인 링(베인·다리). 동체 튜브 없음 | rev B 그대로. CAD는 §3.4 참고(SolidGeek Onshape 포크 권장, 자체 `cad/*.scad`는 대안으로 유지) |
| L5 | 아비오닉스·배터리 | 중앙부 기둥에 트레이/스트랩으로 장착, 기류 밖. CG 트림용 세로 이동 | rev B 그대로 |
| L6 | 착륙장치 | **고정형** 다리 4개(전개 서보 없음). 보조 MCU 없음 | CLAUDE.md 단순화 |
| L7 | 스코프 | 1차: 구속 자세 안정화 비교(주력) / 2차: 저고도 홉 반복 (TWR ~2.0로 여유) | rev B 그대로 |
| L8 | 제작 | 3D프린터·전동공구·납땜·CNC 가능. 레이저 커터 없음 | 부장 확정 |
| L9 | 구속 스탠드 | 카메라 삼각대/모노포드 + **저마찰 자유회전 조인트**(십자축 만능조인트+스러스트 베어링 — 사진용 볼헤드 아님) | rev B 확정, 구매 전 정정 반영됨 |
| L10 | **자이로스코픽 정차 보정** | ESC RPM 텔레메트리 + 각속도로 정차 토크를 상쇄하는 피드포워드 항을 레이트 루프에 추가 | Bresciani/PX4 PR #21489 이식. §6.7 |

**아직 안 정한 것 → §14.**

---

## 1. 이 rev의 근거 요약 (전체 논증은 리서치 문서)

`research-open-source-references.md`에 리서치 전체가 있다. 여기선 설계 결정에 직결되는 것만 요약.

### 1.1 SolidGeek/SingleRotorUAV — 왜 이걸 베이스로 삼나

- Aalborg University 석사논문(2021), 문제정의가 우리 프로젝트와 사실상 동일: *"reusable rocket 기술은
  대부분 학교가 접근 불가 → 안전한 축소 플랫폼으로 그 역학을 재현"*.
- **완전한 CAD**(Onshape, 55개 파트, 브라우저에서 즉시 포크 가능) + **완전한 펌웨어**(Teensy 4.0, C++
  전체) + **89쪽 논문**(뉴턴-오일러 동역학 유도, 베인 공력 모델, LQR 제어 설계, 실측 검증 데이터) + 실비행
  영상. **MIT 라이선스.**
- 원본은 추진계가 우리와 다르다(동축 반대회전 오픈프롭 2개, EDF 아님) — 그런데 저자가 논문 토의(8.2절)에서
  본인 입으로 *"실전에서는 단일 모터 덕티드팬(EDF)이 더 나은 선택이었을 것"*이라 결론 냈다. 우리는 처음부터
  단일 EDF를 골랐으니(CLAUDE.md), **CAD·센서·통신·제어 구조는 가져오고 추진계만 원래 계획대로 유지**하면
  저자의 실패를 자동으로 피해간다.
- 부가 소득: 논문의 동역학·베인 공력 방정식을 `sim/hopper_aviary.py`에 그대로 이식 가능 — 시뮬레이션(=RL
  준비) 착수 시간도 앞당겨진다. 이건 "엔지니어링 시간을 깎는" 게 아니라 **정확히 우리가 쓰고 싶은 소프트웨어
  작업의 기반을 앞당기는 것.**

### 1.2 Bresciani(PX4 코어 개발자) — 왜 자이로스코픽 정차 보정을 추가하나

- 90 mm 단일 EDF + 베인4 드론을 직접 만들어 날렸고, [PX4 PR #21489](https://github.com/PX4/PX4-Autopilot/pull/21489)에서:
  > *"빠르게 도는 단일 로터의 자이로스코픽 토크가 롤-피치를 강하게 커플링시켜서 튜닝을 거의 불가능하게
  > 만든다."*
- 해법: 로터 RPM(ESC 텔레메트리) × 각속도로 정차 토크를 실시간 상쇄하는 피드포워드 항. PX4 전체를 채택하지
  않아도 **이 수식만 Teensy 코드에 이식 가능** — SolidGeek 코드가 이미 DShot으로 RPM을 읽고 있어 인프라가
  갖춰져 있다.
- 우리 64mm EDF도 "빠르게 도는 강체 로터"라 같은 문제를 겪을 수 있다 — rev B엔 없던 리스크였는데 이번에
  발견해서 지금 대응을 박아둔다(§6.7, §12).
- 독립적 교차검증: Bresciani 본인이 같은 포럼에서 *"CG를 더 높였더니 안정성이 좋아졌다"*고 언급 — 우리가
  이미 §5.3에서 채택한 "CG를 최대한 높인다" 원칙과 정확히 일치.

### 1.3 왜 이게 "설계 이탈"이 아닌가

CLAUDE.md는 처음부터 "저예산 대안: Arduino/Teensy + 자체 PID"를 명시해뒀다. rev C는 그 대안을 **직접
짜지 않고, 검증되고 문서화되고 실비행까지 끝난 오픈소스로 실현**하는 것 — 골격(EDF·베인·RL 2단계 비교)은
전혀 안 바뀌었다.

---

## 2. 참고한 선행 사례

| 사례 | 링크 | 우리가 가져온 것 |
|---|---|---|
| **SolidGeek/SingleRotorUAV** (Emil Jacobsen, Aalborg Univ. 석사논문) | [GitHub](https://github.com/SolidGeek/SingleRotorUAV) · [Onshape CAD](https://cad.onshape.com/documents/e833cc23e7ea826c94a116f3/w/362fc8aca947f44850932dcd/e/4721094f67251fa796bbdcbc) · [영상](https://youtu.be/jJKNR2vzTVY) · 논문 PDF(`docs/design/references/`) | **Teensy 4.0 펌웨어 전체(센서·통신·제어), CAD 골격, 동역학·베인 공력 방정식, LQR 제어 구조.** 추진계(동축 오픈프롭)는 안 가져옴 — 단일 EDF 유지 |
| **Mathieu Bresciani (PX4 코어 개발자)** | [Printables](https://www.printables.com/model/722967-ducted-fan-thrust-vectoring-drone) · [PX4 PR #21489](https://github.com/PX4/PX4-Autopilot/pull/21489) · [영상](https://www.youtube.com/watch?v=u2cETOyuJ20) | **자이로스코픽 정차 보정 로직**(로터 RPM 피드포워드), "CG는 높을수록" 교차검증 |
| **bribro12 — SpaceX-inspired EDF rocket** | hackster.io/bribro12 | 추진계 실측 근거(70mm급 EDF 스펙), "내부 배선이 기류 방해" 교훈 — 오픈프레임 채택 근거 |
| **cjhagemeyer — 64mm EDF용 3축 TVC** | printables.com/model/803977 | 64mm 스케일 베인 하우징 기하 참고 |
| **K-9 TVC Hopper Test Vehicle** | printables.com/model/164897 | 4다리 배치 기하 참고 |
| **fdiwth/tvc-drone** (검토 후 기각) | github.com/fdiwth/tvc-drone | 참고 안 함 — 코액시얼+짐벌 방식(우리와 다른 액추에이션), 커스텀 PCB 필요(엔지니어링 시간 증가), 비행 성공 미검증, 제작자 본인이 "따라하지 말라"고 명시 |
| Carholt et al. 2016 (MED 컨퍼런스) | [전문 PDF](http://kth.diva-portal.org/smash/get/diva2:1672182/FULLTEXT01) | SolidGeek 논문의 선행연구 — "SR-UAV"라는 학술 하위분야가 실재한다는 근거(발표용) |

---

## 3. 시스템 아키텍처

### 3.1 전체 배치 — 오픈 스탠드오프 프레임 (rev B와 동일 형상)

```
              ╭───────────╮   상단 베일(3 mm 스틸봉) = 손잡이 + M3 텐서 걸이
             ╱             ╲
        ┌───┴───────────────┴───┐  상판 (프린트/합판 3~4 mm)
        │   [ 64 mm EDF, 하향 ]  │  흡기 ▲ 위(상판 위 개방) / 배기 ▼ 아래
        └──┬──┬───────────┬──┬──┘
           │  │           │  │       ← 기둥 4개 (M4 CF튜브/알루, 길이 ~200 mm)
           │ ┌┴───────────┴┐ │
           │ │ 배터리 4S    │ │       ← 중앙 트레이: 배터리 / Teensy4.0 / BNO085 /
       ○───┼─┤ Teensy·ESC   ├─┼───○     ESP32 / DShot ESC. 기류 밖. ±20mm CG 트림
           │ └┬───────────┬┘ │
           │  │           │  │
        ┌──┴──┴───────────┴──┴──┐  하부 베인 링 (프린트)
      ╱ │  ✚   ✚   ✚   ✚        │ ╲     베인 4개 @90°, EDF 배기면 −20~30 mm
    다리 │  서보4 (방사, 기류밖)  │ 다리   ±15° 하드스톱
      ╲ └───────────┬───────────┘ ╱
                  ▼▼▼▼                배기(하향)
       ▂▂▂         제트         ▂▂▂    발 4개, 배기면 −140 mm, 발원 ~360 mm
```

기구 형상(치수·질량·TWR)은 **rev B와 동일** — 바뀐 건 상판/트레이 안에 들어가는 전자부품 구성뿐이다.
따라서 §4~5(치수·질량예산)는 그대로 유효하고, 아래 §6.5·§6.7·§7·§8만 이번 rev의 실제 변경 지점이다.

### 3.2 CAD 소스 — 어디서 시작하나

| 경로 | 방법 | 권장 |
|---|---|---|
| **A. SolidGeek Onshape 포크** | [원본 문서](https://cad.onshape.com/documents/e833cc23e7ea826c94a116f3/w/362fc8aca947f44850932dcd/e/4721094f67251fa796bbdcbc)를 COSMOS Onshape 계정으로 "Copy" → 모터마운트를 F40 오픈모터용에서 우리 EDF 마운트로 교체 → 나머지(Vector Fin=베인, Leg/Leg Piston, Top, PCBS 마운트)는 치수만 조정 | **1순위** — 브라우저 기반이라 진입장벽 낮고, "Test Bench Assembly" 파트 스튜디오도 있어 구속 스탠드 설계도 참고 가능 |
| B. 자체 파라메트릭(`cad/params.scad` 등) | rev B에서 이미 작성한 OpenSCAD 스케치 계속 사용 | 대안 — Onshape 포크가 안 풀리거나 팀이 OpenSCAD에 더 익숙하면 |

두 경로 다 **최종 결과물의 물리 사양(치수·질량·TWR·베인 크기)은 §4~6.3에 이미 고정된 값을 따라야 한다** —
CAD 툴만 다를 뿐, 형상 스펙은 동일.

---

## 4. 좌표계 · 전체 치수 (rev B와 동일 — 그대로 유효)

| 치수 | 기호 | 값 (DESIGN) | MEASURED | 비고 |
|---|---|---|---|---|
| EDF 하우징 외경 | `edf_housing_od` | 67 mm (가정) | ___ | 64 mm 팬 + 립. 실측 필수 |
| EDF 마운트 볼트 PCD | `edf_mount_pcd` | 76 mm (가정) | ___ | 제품마다 다름 |
| 기둥 길이(상판~베인링) | `col_len` | 200 mm | ___ | 아비오닉스 스택 높이로 조정 |
| 상판 두께 | `top_plate_t` | 4 mm | ___ | |
| 베인 링 높이 | `vane_ring_h` | 28 mm | ___ | |
| EDF 배기면 → 베인 피벗축 | `vane_gap_below_exit` | 22 mm | ___ | |
| EDF 배기면 → 발 바닥 | `foot_below_exit` | 140 mm | ___ | |
| 전체 높이(베일 팁~발) | `H_total` | ≈ 350 mm | ___ | |
| 발 원 지름 | `foot_circle` | 360 mm | ___ | |
| 다리 길이(로드) | `leg_len` | 210 mm | ___ | |
| 다리 스플레이 | `leg_splay` | 33° | ___ | |
| 베인 시위/스팬/두께 | — | 25 / 45 / 2.5 mm | ___ | §6.3 |
| 베인 최대 편향(기계) | `vane_deflect_max` | ±15° | ___ | |
| CG 위치(배기면 기준) | `x_cg` | 140~180 mm 목표 | ___ | |

정본: SolidGeek Onshape 포크 사용 시 그 모델, 자체 CAD 사용 시 `cad/params.scad`. 이 표는 양쪽 다 지켜야
할 목표 스펙.

---

## 5. 질량 · CG · 추력 예산 (rev B 수치 유지, 아비오닉스만 소폭 재계산)

### 5.1 질량 예산 (rev C)

| 항목 | 질량 (g) | rev B 대비 | 비고 |
|---|---:|---|---|
| 64 mm EDF 팬+모터 (4S) | 160 | 동일 | |
| 60 A ESC (4S, **양방향 DShot**) | 40 | 동일 | 텔레메트리 지원 여부는 무게에 안 영향 |
| 4S 1300 mAh 65C LiPo | 150 | 동일 | |
| **Teensy 4.0** | 5 | F405(12g) 대비 **-7** | 보드가 훨씬 작음 |
| **BNO085 브레이크아웃** | 3 | (신규) | |
| **ESP32 개발보드** | 10 | (신규) | |
| RC 수신기 | 6 | 동일 | |
| 서보 4× MG90S (9 g) | 55 | 동일 | |
| 베인 링 + 베인4 + 링키지 (프린트) | 70 | 동일 | |
| 상판 + 베일 + 기둥4 + 트레이 | 90 | 동일 | |
| 착륙 다리 4 | 70 | 동일 | |
| 배선·스트랩·타이·에폭시 | 50 | +5 (배선 부품 늘어남) | |
| **합계 (AUW)** | **≈ 660 g** | **+10 g** | 오차범위 내, TWR 영향 미미 |

### 5.2 TWR — rev B와 사실상 동일

- 64 mm/4S 정적 추력 1,300 gf 기준 → **TWR ≈ 1,300 / 660 ≈ 1.97.** (rev B: 2.0)
- 구속 시험(≥1.15)·저고도 홉(≥1.6) 기준 모두 여전히 여유 있게 충족.

### 5.3 CG · 관성 — rev B와 동일 원칙, Bresciani 교차검증 추가

- 목표 CG: 배기면 위 140~180 mm. 트리밍: 중앙 트레이 ±20 mm 슬라이드.
- **Bresciani가 독립적으로 검증**: "CG를 높였더니 안정성이 좋아졌다" — 같은 원칙, 다른 팀, 같은 결론.
- 관성 텐서 측정 방법(2선/비틀림 진자)은 rev B와 동일. 논문 3장의 관성 추정 방법론도 참고 가능.

---

## 6. 서브시스템 상세 설계

§6.1(프레임)·§6.2(EDF)·§6.3(베인)·§6.4(다리)·§6.6(구속 인터페이스)는 **rev B와 완전히 동일** — 아키텍처가
안 바뀌었으므로 재수록하지 않는다(BOM.md·이전 rev 참고). 아래는 **rev C에서 바뀌거나 새로 생긴 것만.**

### 6.5 아비오닉스 · 배선 (rev C — 교체)

- **비행 컴퓨터**: Teensy 4.0. SolidGeek 코드(`firmware/reference/SingleRotorUAV/`에 원본 vendor-copy
  있음)를 포크해서 사용.
- **IMU**: BNO085 (BNO080 핀호환 후속, SPI 버그 수정판). I2C 또는 SPI로 Teensy에 연결. 센서퓨전이 칩
  내장이라 Teensy는 쿼터니언을 바로 받는다 — 별도 상보/칼만 필터를 자세추정에 안 짜도 됨(그 대신 위치추정용
  칼만필터는 논문 5장 구조를 따름).
- **고도/위치 센서 (STAGE 3+ 전용, STAGE 1엔 불필요)**: VL53L1X ToF 라이다(고도), PMW3901 광류(수평
  위치) — SolidGeek 코드에 드라이버 이미 포함. 구속 시험 단계에선 배선만 해두고 안 써도 무방.
- **통신**: ESP32를 Teensy와 UART로 연결, WiFi로 노트북(지상국)과 텔레메트리·로깅. RC 수신기는 별도로
  Teensy에 직결(페일세이프/수동 오버라이드).
- **배선 원칙**: rev B와 동일 — 전부 기류 밖. 트레이 안에서 Teensy-BNO085-ESP32-ESC 간 배선 완결.
- **질량 대칭**: rev B와 동일 원칙.

### 6.7 자이로스코픽 정차 보정 (rev C — 신규)

- **문제**: 64 mm EDF 팬은 강체 로터가 고속 회전 — 각운동량이 커서, 기체가 롤/피치로 회전할 때 자이로스코픽
  토크가 발생해 두 축을 서로 커플링시킨다. Bresciani(PX4)에 따르면 이게 "튜닝을 거의 불가능하게" 만들 수
  있음.
- **해법(이식 대상)**: PX4 PR #21489의 피드포워드 항 —
  ```
  τ_precession ≈ H_rotor × ω_body   (H_rotor = 로터 각운동량 = I_rotor·Ω, ESC RPM 텔레메트리로 Ω 획득)
  ```
  레이트 컨트롤러 출력에 `-τ_precession`를 더해 상쇄. Teensy 쪽엔 `src/dshot.cpp`가 이미 양방향 DShot로
  RPM을 읽는 구조라 큰 개조 없이 추가 가능.
- **대안/병행**: SolidGeek의 LQR(전상태 궤환)은 이 커플링을 명시적으로 모델링하진 않지만, 게인행렬이 암묵적
  으로 어느 정도 흡수한다(논문 8.1.1절 참고, 실측에서 큰 문제 없이 비행 성공). **정차 보정 없이 LQR만으로도
  일단 시도해보고, TC-3에서 롤-피치 커플링이 실제로 문제되면 그때 보정 항을 추가하는 순서를 권장** — 처음부터
  두 개를 다 구현하려 하지 않는다.
- **필요 조건**: ESC가 RPM을 리턴해야 하므로 §BOM A2(양방향 DShot 필수)와 직결.

---

## 7. 전자 계통 · 배선도 (rev C — 교체)

```
        4S LiPo (14.8 V)  XT60
            │
     ┌──────┴──────┐  물리 킬스위치 (인라인)
     └──────┬──────┘
     ┌──────┴──────────────────┐
  60A ESC(양방향DShot) ──3φ──▶ 64mm EDF 모터   (메인 전류, 40~52 A)
     │   └─ BEC 5~6V ──┐        RPM 텔레메트리 ─┐
     │                 │                        │
  Teensy 4.0 ◀─────────┴────────────────────────┘  (DShot 신호선 1개로 제어+RPM 왕복)
     │  ├─ I2C/SPI ── BNO085 (IMU, 쿼터니언)
     │  ├─ PWM ×4 ── 베인 서보 (Fwd/Right/Back/Left)
     │  ├─ UART ── ESP32 (WiFi 텔레메트리 → 노트북 지상국)
     │  ├─ RC 입력 ── 수신기 (SBUS 또는 Spektrum DSM 시리얼, 킬 채널 포함)
     │  └─ (STAGE3+) I2C ── VL53L1X / SPI ── PMW3901
```

- BEC 전원과 서보 전원 공통 레일 확인, 필요 시 UBEC(A5)로 이중화.
- BNO085는 모터·ESC 전류경로에서 최대한 띄워 장착(SolidGeek 논문이 지적한 자기간섭 회피 — 단, 우리는
  자력계 자체를 안 쓰므로(자이로 적분) 영향은 제한적이지만 진동원에서 거리는 확보).
- ESP32 로깅이 곧 PID/RL 비교 실험의 원자료가 된다 — 배선 우선순위 높게.

---

## 8. 비행 제어 설정

### 8.1 Teensy/SolidGeek 포크 (주 경로, rev C)

1. `firmware/reference/SingleRotorUAV/`(원본 vendor-copy)를 기준으로 실제 빌드용 포크 생성.
2. **프로펄전 믹서 단순화**: 원본은 `write_motor()`를 2회(듀얼 모터) 호출 — 우리는 1회(단일 EDF)로. 이 부분이
   가장 큰 코드 수정 지점이지만, 오히려 원본보다 **로직이 단순해진다**(모터 간 밸런싱 로직 삭제 가능).
3. 베인 믹서(`write_servo(0..3, ...)`)는 원본 그대로 사용 가능 — 우리와 동일한 4베인 구조.
4. IMU 드라이버(`BNO080.cpp`)는 BNO085도 핀/레지스터 호환이라 그대로 사용.
5. DShot 드라이버(`dshot.cpp`)에 §6.7의 정차 보정 항을 추가(선택, TC-3 결과 보고 판단).
6. 제어 구조는 원본의 `control_hover()`(LQR, `output = K * error`)를 그대로 시작점으로 — 우리 기체
   질량·관성으로 게인행렬만 재설계(§8.3).
7. **RL 이식 지점**: `control_hover()`의 `output = K * error;` 한 줄을 나중에 "정책망 추론 호출"로
   교체하는 구조를 처음부터 염두에 두고 리팩터링.

### 8.2 튜닝 절차 (구속 M1)

1. 논문 4장(Control) 방식대로 선형화 모델 → LQR 게인 1차 설계(가중행렬 Q, R은 논문 사례를 시작값으로).
2. 구속 상태에서 게인 낮게 시작 → 발산 없는지 확인 → 점진적으로 상향.
3. TC-3에서 롤-피치 커플링(자이로 정차) 관찰 → 문제되면 §6.7 보정 항 추가.
4. 모든 세션 ESP32로 로깅(§7) — RL 비교의 baseline 데이터.
5. **참고**: 논문 8.1.3절 — 적분기 anti-windup 한계를 너무 낮게 잡으면 정상상태오차가 남는다는 실측 교훈.
   우리도 적분 게인·리밋을 설계 초기부터 로깅하며 잡을 것.

### 8.3 게인 설계 시작값

- SolidGeek 논문 4.1.2절(LQR)·Appendix의 Q/R 가중치, K 게인행렬을 1차 참고. 우리 기체(660 g, rev B와
  다른 질량·관성)에 맞게 반드시 재설계 — 그대로 쓰면 안 됨(논문 8.1.1절도 "질량이 다르면 언더댐프"된다고
  명시).
- 순수 PID로 시작하고 싶으면 balancing-beam 시작값(Kp 1.3 / Ki 5e-4 / Kd 0.9)도 여전히 유효한 대안.

### 8.4 대안 경로 — ArduPilot SingleCopter (보존)

rev B에서 검증해둔 F405 WING + ArduPilot SingleCopter 경로는 **폐기하지 않고 대안으로 보존**한다.
Teensy/SolidGeek 포크가 예상보다 막히면(예: BNO085 드라이버 이식 실패, LQR 튜닝이 너무 오래 걸림)
언제든 전환 가능하도록 `firmware/singlecopter.param.md`를 그대로 유지한다. 두 경로 모두 같은 기구(§3~6)를
쓰므로 기구 작업은 낭비되지 않는다.

---

## 9. 시뮬레이션 · RL 인터페이스 요구사항

> ⚠️ **이 절은 rev B 잔재였다 — 2026-09-18 폐기.** 아래 obs(12)/act(4) 스펙은 실제 구현
> (`sim/sim_stage1/hopper_aviary.py`, obs 6·act 5차원)과 이미 어긋나 있었다(`sim/README.md`가 이미
> "이전 계획의 12/4차원 문서와 다름, 이게 현재 정답"이라고 지적해둔 상태였음 — 이번에 원 소스를 고침).
> **정본은 이제 [`03-control-pipeline-design.md`](03-control-pipeline-design.md) §4**(State/Action
> Space, Stage별 구분 포함)·§5(Domain Randomization 갭 분석)·§2(3D 물리엔진 전환 로드맵)다. 아래는
> 옛 표를 삭제하고 남긴 자리 — 새로 뭔가 적지 않는다, 위 문서로 간다.

---

## 10. 제작 순서 (rev C)

1. **핵심 부품 먼저 구매** — EDF, Teensy 4.0, BNO085, 양방향 DShot ESC (BOM-revC-teensy.md §구매순서).
2. **CAD 착수** — SolidGeek Onshape 문서 Copy(포크) → 모터마운트 교체 → 실측값 반영(§3.2, §4).
3. **펌웨어 포크** — `firmware/reference/SingleRotorUAV/` 원본을 베이스로 실 빌드용 리포/브랜치 생성,
   Teensy 4.0 대상 컴파일 확인(하드웨어 없이도 가능).
4. **프린트 (PETG)** — 상판 → 베인링+베인4 → 기둥 소켓 → 트레이 → 다리 발.
5. **베인링 조립** — CF 스파, 부싱, 서보, 링키지, ±15° 스톱 확인.
6. **기둥 결합** — 상판↔베인링, 직각·비틀림 확인.
7. **다리** — 재단·접착·볼트.
8. **전자 조립** — Teensy·BNO085·ESP32·DShot ESC·RX. 배선 전부 기류 밖.
9. **질량·CG·관성 측정** → `sim/params.yaml`.
10. **밸런스** — CG 트림.
11. **소프트웨어 셋업** — 펌웨어 플래시, RC/DShot/BNO085 개별 검증(TC-1 전 단계).
12. **M1 삼각대 마운트** 준비, 킬 2중 확인.
13. **시험 카드** (§11).

---

## 11. 시험 카드 (CLAUDE.md 안전 순서와 1:1, rev B와 동일 — 도구만 Mission Planner→Teensy 시리얼/ESP32 지상국으로 교체)

| TC | 이름 | 구속 | 합격 기준 | 중단 |
|---|---|---|---|---|
| **TC-0** | 스로틀 온리 | M1 | 20~60% 스로틀에서 진동 RMS < X, 이상음/열 없음, EDF 마운트 유격 0 | 이상진동·연기·유격 |
| **TC-1** | 베인 방향 검증 | M1 | 수동 입력 → 롤=Fwd/Back, 피치=L/R, 요=4캔트. 부호 일치 | 반대부호 → 믹서 부호 수정 |
| **TC-2** | 베인 힌지모멘트·제어효과 실측 | 베인링만 스탠드 | 15° 유지 시 서보 온도 <45°C, ∂M/∂δ 기록 | 서보 스톨·과열 |
| **TC-2.5** *(신규)* | **자이로 정차 커플링 관찰** | M1 | 스로틀 고정 후 롤 스텝 입력 → 피치 응답 크기 기록. 크면 §6.7 보정 필요 판단 | — |
| **TC-3** | 자세 안정화(LQR/PID) | M1 | ±10° 초기오프셋 복원시간 τ, 오버슈트, 정상오차 기록. 발산 없음 | 리미트사이클 발산 |
| **TC-4** | 외란 강인성 | M1 | 임펄스 외란·배터리 새그 복원. baseline 확정 | — |
| **TC-5** | RL 정책 비교 | M1 | TC-3·4와 동일 조건 반복, 비교표 (발표 핵심) | 정책 이상 → 즉시 킬 |
| **TC-6** | 추력·지면효과 | M2 | 호버 스로틀 %, 지면효과 특성 | — |
| **TC-7** | 저고도 홉 (반복) | M3 → 점차 완화 | STAGE 3 데이터 확보 + 추력 실측 전제 | 자세 발산·하드랜딩 |

---

## 12. 리스크 레지스터

| 리스크 | 출처 | 대응 |
|---|---|---|
| **자이로스코픽 정차 커플링 — 튜닝을 거의 불가능하게 만들 수 있음** *(rev C 신규)* | Bresciani, PX4 PR #21489 | TC-2.5로 조기 관찰, §6.7 보정 항 이식 경로 확보(ESC RPM 텔레메트리 필수 — BOM에 반영됨) |
| 동축/듀얼모터로 토크 상쇄 시도는 실전에서 실패 | SolidGeek 논문 8.2절 | 우리는 단일 EDF라 해당 없음 — "우리가 옳았다"는 근거로만 기록 |
| IMU-모터 자기간섭으로 요 드리프트 | SolidGeek 논문 8.1.1절 | 자력계 미사용(자이로 적분)으로 이미 회피 |
| 착륙 단계는 호버 게인으로 부족 | SolidGeek 논문 8.1.2절 | TC-7 설계 시 착륙 전용 게인 스케줄 고려 |
| 조립 후 베인·다리 간섭 | BPS.Space | CAD 스윕 볼륨 확인(Onshape/`cad/` 양쪽 다) |
| 서보 피로·핀조인트 응력 | arXiv 2509.00061 | 금속기어, CF 스파, TC-2 실측 |
| **Teensy 포크가 예상보다 막힘** *(rev C 신규)* | — | §8.4 ArduPilot/F405 대안 경로 보존 — 기구는 공유되므로 전환 비용 낮음 |
| sim 낙관 편향 | ROBOMECH | DR 범위 넓게, STAGE 3에서 실측 |
| 요 축 권한 약함 | SingleCopter/모노콥터 공통 | 저게인/구속, 발표에 한계 명시 |
| LiPo 화재 / EDF 흡입 | 안전 일반 | rev B 안전 원칙 그대로(세이프백·1C·물리킬·그릴·보안경) |
| 오픈프레임 = 부품 노출 | rev B 고유 | 시험구역 스크린, 예비 기체, 배선 절연 |

---

## 13. BOM

**상세 구매 리스트 → [`BOM-revC-teensy.md`](BOM-revC-teensy.md)** (rev C 현행, 총계 ≈ ₩350k–620k).

`BOM.md`(rev B)는 추진·베인·구조·구속·안전 항목은 여전히 유효하나, **비행컴퓨터/센서/통신 섹션(B)은
BOM-revC-teensy.md로 대체됨** — 그쪽 문서에 상단에 명시해둠.

---

## 14. 아직 안 정한 것

| 항목 | 필요 정보 | 언제 |
|---|---|---|
| 64 mm EDF 정확 모델·실측 추력·하우징 치수 | 구매·실측 + 추력 스탠드 | 제작 1 / STAGE 1 |
| CAD 경로 — SolidGeek Onshape 포크 vs 자체 `cad/*.scad` | 팀 CAD 숙련도·선호 | 제작 2 전 |
| 수신기 — 기존 Spektrum 재사용 vs 신규 SBUS 구매 | 재고 확인 | 구매 전 |
| 정차 보정을 처음부터 넣을지, TC-2.5 보고 판단할지 | TC-2.5 결과 | STAGE 1 |
| LQR vs PID 중 어느 걸 "baseline"으로 삼을지(혹은 둘 다 비교) | 팀 논의 | STAGE 1 착수 전 |
| 최종 CG·관성 | 조립 후 측정 | 제작 9 |
| 홉 고도 상한·시점 | STAGE 3 결과 | STAGE 4 |
| 쉬라우드(외피) 부착 여부 | 발표 외형 선호 | STAGE 4 전(선택) |

---

## 15. 참고문헌

- Jacobsen, E.B. *Modelling and Control of Thrust Vectoring Mono-copter*, Aalborg University 석사논문, 2021 — 전문: `docs/design/references/`, 코드: `firmware/reference/SingleRotorUAV/`, [GitHub](https://github.com/SolidGeek/SingleRotorUAV), [Onshape](https://cad.onshape.com/documents/e833cc23e7ea826c94a116f3/w/362fc8aca947f44850932dcd/e/4721094f67251fa796bbdcbc)
- Bresciani, M. — [단일 EDF TVC 드론(Printables)](https://www.printables.com/model/722967-ducted-fan-thrust-vectoring-drone) · [PX4 PR #21489](https://github.com/PX4/PX4-Autopilot/pull/21489) · [영상](https://www.youtube.com/watch?v=u2cETOyuJ20)
- Carholt, O.C. et al. *Design, modelling and control of a Single Rotor UAV*, MED 2016 — [전문 PDF](http://kth.diva-portal.org/smash/get/diva2:1672182/FULLTEXT01)
- bribro12, *SpaceX inspired EDF rocket* — hackster.io/bribro12
- cjhagemeyer, *3-axis thrust vectoring for 64mm EDF* — printables.com/model/803977
- K-9 TVC Hopper Test Vehicle — printables.com/model/164897
- *Design and Testing of a Low-Cost 3D-Printed Servo Gimbal for TVC* — arXiv:2509.00061
- ArduPilot, *SingleCopter and CoaxCopter*(§8.4 대안 경로용) — ardupilot.org/copter/docs/singlecopter-and-coaxcopter.html
- utiasDSL, *gym-pybullet-drones* — github.com/utiasDSL/gym-pybullet-drones
- 전체 리서치 근거: [`research-open-source-references.md`](research-open-source-references.md)

---

## 16. 첨부 자료 모음

| 자료 | 위치/링크 |
|---|---|
| 이 마스터 설계도 | `docs/design/00-hopper-master-design.md` (이 파일) |
| 리서치 전체(비교표·리스크·의사결정 근거) | `docs/design/research-open-source-references.md` |
| 구매 리스트(rev C) | `docs/design/BOM-revC-teensy.md` |
| 구매 리스트(rev B, 기구 파트는 유효) | `docs/design/BOM.md` |
| 개략 배치도 | `docs/design/general-arrangement.svg` |
| **SolidGeek 논문 전문(PDF, 89쪽)** | `docs/design/references/Jacobsen2021_Modelling-and-Control-of-Thrust-Vectoring-Mono-copter.pdf` |
| **SolidGeek 펌웨어 원본(vendor copy)** | `firmware/reference/SingleRotorUAV/` (`ORIGIN.md`에 출처·라이선스·수정계획 명시) |
| SolidGeek CAD(Onshape, 라이브) | https://cad.onshape.com/documents/e833cc23e7ea826c94a116f3/w/362fc8aca947f44850932dcd/e/4721094f67251fa796bbdcbc |
| ArduPilot 대안 경로 파라미터 | `firmware/singlecopter.param.md` |
| 자체 CAD 스케치(대안) | `cad/params.scad`, `cad/top_plate.scad`, `cad/vane_ring.scad` |

---
*rev C — 비행 컴퓨터/펌웨어 베이스 교체 확정. 기구·추진·질량·시험절차는 rev B에서 계승.
다음 갱신은 실측값 반영(rev C.1) 또는 CAD 경로 확정 후.*

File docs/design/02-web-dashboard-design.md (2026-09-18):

# 웹 대시보드 · 3D 인터페이스 — 설계도 (신규, 2026-09-18)

COSMOS PRJ-01. **이 문서가 "소프트웨어팀 웹 산출물"의 단일 진실 소스다.**
`sim/`(RL 학습)·`firmware/`(실기 제어)는 이미 각자 README가 있는데, 이 프로젝트의 **세 번째 소프트웨어
축 — "PID vs RL 비교를 보여주는 웹 화면 + 우리 기체의 3D 인터페이스"** — 는 지금까지 "웹으로 구현할 생각"
한 문장 말고는 스펙이 하나도 없었다. 이 문서가 그 스펙이다.

**이 문서를 쓰는 이유**: 부장이 소프트웨어팀에게 "정확히 뭘 만들어야 하는지"를 설명 못 하고 있었다.
아래를 읽으면 ①왜 이게 필요한지 ②정확히 뭘 만드는지 ③어떤 데이터를 어디서 받는지 ④무슨 기술로
시작하면 되는지가 다 나온다.

---

## 0. 범위·전제

| 항목 | 내용 |
|---|---|
| 이 문서가 다루는 것 | 웹 대시보드(비교 차트) + 3D 자세 뷰어의 목표·아키텍처·데이터 계약·기술 선택 |
| 이 문서가 안 다루는 것 | RL 학습 자체(`sim/README.md`가 정본), 펌웨어 제어로직(마스터 설계도 §8), 기구·전자(00/01번 문서) |
| 전제 | `AGENTS.md`의 "PID vs RL 비교 실험 프로토콜"과 `00-hopper-master-design.md` §11 시험카드(TC-0~TC-7)를
  **그대로 데이터 소스로 삼는다** — 이 문서는 새 실험을 만들지 않고, 이미 확정된 실험 결과를 **보여주는** 층이다 |
| 팀 배치 | 기존 3팀(기구·전자 / 소프트웨어 / 실험·운영) 중 **소프트웨어팀 내부의 서브트랙**. RL 서브트랙과 별개로
  진행 가능(§6) — 웹 UI는 실측 데이터를 기다리지 않고 지금 바로 착수 가능 |

---

## 1. 왜 이게 필요한가

홍보 발표(`docs/presentation/speaker-notes.md`, 2026-09-05)에서 이미 약속한 내용:

> "같은 하드웨어, 같은 임무 조건에서 PID와 강화학습 정책을 각각 올려보고, 복원 시간이나 정상상태 오차
> 같은 지표로 **정량적으로 직접 비교**하는 것이 이번 프로젝트의 진짜 핵심이고, 실제로 어느 쪽이 더 나은
> 성능을 내는지를 **데이터로 증명**하는 게 목표입니다."

"데이터로 증명"이 실제로 되려면 그 데이터를 **보여줄 화면**이 있어야 한다. 지금 상태:

- 데이터는 나온다 — Teensy가 USB 시리얼로 CSV를 찍는다(`01-avionics-integration-final.md` §3.5), RL
  학습도 로그를 남길 수 있다.
- 근데 그걸 볼 방법이 CSV 파일을 텍스트 에디터로 여는 것밖에 없다. **비교표·그래프·발표자료가 전부
  수작업**이 된다는 뜻.
- "3D 인터페이스"는 장식이 아니라 **디버깅 도구**이기도 하다 — TC-1(베인 방향 검증, 마스터 §11)에서
  "롤 명령 → 실제로 롤 방향 베인이 움직였나"를 눈으로 확인하는 게 지금은 사람이 기체를 보면서 확인하는
  방식뿐인데, 3D 뷰어가 있으면 로그만으로도 사후 검증이 된다.

**결론: 이 웹 앱이 곧 발표 핵심 자료(슬라이드 6 "비교 실험"의 실제 산출물)다.** 장식용 사이드 프로젝트가
아니라, 이게 없으면 "데이터로 증명"이라는 프로젝트의 핵심 약속을 못 지킨다.

### 1.1 이 문서의 3D와 RL 훈련용 3D 물리엔진은 다른 것이다 — 혼동 금지

소프트웨어팀 내부에서 제일 헷갈리는 지점이라 먼저 못박는다. RL 트랙에도 3D가 따로 있다
(`03-control-pipeline-design.md` §2, Stage 2 물리엔진 전환) — **이 문서의 3D 뷰어와는 목적이 다르다.**

| | 이 문서의 웹 3D 뷰어 | RL 훈련용 3D 물리엔진(`03-control-pipeline-design.md`) |
|---|---|---|
| 역할 | 이미 계산된 로그(CSV)를 **그대로 재생**한다 — 물리 연산 없음 | **물리를 계산**한다(충돌·강체동역학·공력) — RL이 학습하는 대상 |
| 언제 쓰나 | 시험 후/발표 시 결과를 보여줄 때 | 학습 중(팀 PC에서, 보통 헤드리스로 수백만 스텝) |
| 기술 | JavaScript + Three.js | Python + PyBullet(후보, §2) |
| 입력 | CSV의 이미 기록된 자세값 → 그대로 회전만 | RL 액션 → 물리엔진이 다음 상태 계산 |
| 공유 자산 | **같은 3D 모델(URDF/mesh)을 재사용 가능** — CAD 트랙이 STL을 한 번만 export하면 양쪽에서 씀 | 위와 동일 |

**한 줄 규칙**: 물리 계산이 필요하면 `03-control-pipeline-design.md`의 시뮬레이터, 그냥 보여주기만
하면 이 문서의 웹 뷰어. "RL을 3D로 한다"는 이 문서가 아니라 그 문서 얘기다 — 이 문서는 어디까지나
**결과를 보여주는 뷰어**.

---

## 2. 정확히 뭘 만드는가 (산출물 정의)

하나의 웹 앱(SPA) 안에 아래 3개 화면/기능이 들어간다. **셋 다 같은 CSV 데이터(§4)를 읽는다** — 데이터
소스가 하나라 화면만 3개인 구조.

### 산출물 A — 비교 대시보드 (발표 핵심)

- TC-3(baseline 안정화)·TC-4(외란 강인성)·TC-5(RL 비교) 로그를 불러와서:
  - 자세각(φ,θ,ψ) 시계열 그래프 — PID 런 vs RL 런을 **같은 그래프에 겹쳐서** 표시
  - 지표 요약 테이블: 복원시간(τ)·오버슈트·정상상태오차 (마스터 §11 TC-3 "합격 기준"과 동일 지표)
  - 여러 런(run)을 골라 비교(같은 시험을 N번 반복하니 평균·분산도 보여주면 좋음)

### 산출물 B — 3D 자세 뷰어

- 호퍼 형상(단순화된 3D 오브젝트, §5)을 화면에 띄우고, 로그의 자세값(쿼터니언 또는 φ,θ,ψ)에 맞춰
  **그 오브젝트를 실제로 회전**시킨다.
- **리플레이 모드**(기본, Stage 1) — CSV를 처음부터 끝까지 타임라인 슬라이더로 재생. 녹화된 시험을
  "다시 보기"하는 것.
- **라이브 모드**(스트레치, Stage 2 — ESP32 WiFi 붙은 뒤) — 실시간 텔레메트리를 받아 그 자리에서 회전.
  지금 당장 필요하지 않음(§6 로드맵 참고).

### 산출물 C — 시뮬레이션 뷰어 (RL 트랙과의 연결점)

- RL 학습 에피소드(지금은 `sim/sim_stage1/hopper_aviary.py`, 나중엔 `03-control-pipeline-design.md`
  §2의 Stage 2 물리엔진)도 **같은 스키마(§4)로 CSV export**하면 똑같은 3D 뷰어·차트로 볼 수 있다.
  "시뮬에서 배운 정책이 실기에서 어떻게 다르게 움직였나"를 나란히 보여줄 수 있음 — sim-to-real 격차를
  시각적으로 보여주는 발표 소재. **이때도 웹 앱은 물리를 다시 계산하지 않는다** — sim이 이미 계산해
  export한 CSV를 §1.1과 똑같은 방식으로 재생할 뿐이다.

**셋이 다 "같은 CSV 스키마를 읽는 뷰어"라는 점이 핵심 설계 원칙이다.** 소프트웨어팀이 처음에 헷갈리기
쉬운 지점 — "3D는 비행 시뮬레이터를 새로 만드는 건가?"가 아니라, **이미 있거나 앞으로 나올 로그 데이터를
읽어서 재생하는 뷰어**를 만드는 것이다. 물리 연산은 전혀 안 한다(그건 `sim/`이 이미 함).

---

## 3. 시스템 아키텍처

```
[데이터 소스]                    [프론트엔드 웹 앱]
 data/*.csv (Teensy USB 로그)  ─┐
 sim/.../episode_logs/*.csv    ─┼─►  CSV 파서 (§4 스키마)
 (STAGE 2) ESP32 WiFi 스트림   ─┘         │
                                          ├─► 산출물 A: 비교 차트 (Chart.js/Recharts)
                                          ├─► 산출물 B/C: 3D 뷰어 (Three.js)
                                          └─► 타임라인 슬라이더(리플레이 동기화)
```

- **Stage 1(지금 당장) = 백엔드 없음.** 브라우저가 CSV 파일을 직접 읽는다(파일 업로드 버튼 또는
  `fetch()`로 정적 파일 로드). 배포도 정적 호스팅(GitHub Pages)으로 충분 — 서버 관리·배포 파이프라인
  자체가 필요 없어서 **팀 리소스를 3D/차트 구현에 집중**할 수 있다.
- **Stage 2(ESP32 WiFi 텔레메트리 붙은 뒤, STAGE 2/3) = 경량 백엔드 추가 검토.** WebSocket으로 실시간
  중계가 필요해지면 그때 FastAPI(Python, RL 팀이 이미 익숙) 한 파일짜리 서버를 붙인다. **지금 미리
  만들지 않는다** — YAGNI, 실측 데이터도 없는데 실시간 인프라부터 만들면 우선순위가 뒤집힌다.

---

## 4. 데이터 계약 (Data Contract) — 펌웨어팀 ↔ 소프트웨어팀을 잇는 핵심

**이게 이 문서에서 제일 중요한 표다.** 펌웨어(`firmware/cosmos/`)가 이 컬럼 이름·순서로 CSV를 찍고,
웹 앱이 이 스키마로 파싱하면 두 팀이 서로 코드를 안 봐도 통합된다.

| 컬럼 | 단위 | 의미 | 출처 |
|---|---|---|---|
| `t_ms` | ms | 시험 시작 후 경과시간 | Teensy `millis()` |
| `mode` | 문자열 | `PID` \| `RL` \| `MANUAL` | 펌웨어가 현재 제어모드 태깅 |
| `phi`, `theta`, `psi` | rad | 자세각(roll/pitch/yaw), ZYX 오일러 | BNO085 쿼터니언→오일러 변환 (또는 쿼터니언 4개 원값도 같이 찍으면 §5-3에서 짐벌락 회피 가능) |
| `wx`, `wy`, `wz` | rad/s | 바디 각속도 | BNO085 자이로 |
| `servo1`..`servo4` | µs 또는 -1~1 | FWD/LEFT/AFT/RIGHT 베인 명령값 (`01-avionics-integration-final.md` §1 좌표 규약과 동일 순서) | 펌웨어 믹서 출력 |
| `throttle` | 0~1 | EDF 스로틀 | 펌웨어 DShot 명령 |
| `batt_v` | V | 배터리 전압 | ESC/ADC (있으면) |
| `rpm` | rpm | 로터 RPM (있으면, 자이로 정차 보정용) | 양방향 DShot 텔레메트리 |

- **파일명 규칙은 이미 확정돼 있다** (`01-avionics-integration-final.md` §3.5): `data/YYYYMMDD-TCx-런번호.csv`.
  웹 앱은 이 이름 패턴으로 시험(TC)·날짜·런을 자동 인식하면 편함(예: 파일 목록에서 TC별로 그룹핑).
- **지금 펌웨어 코드(`firmware/cosmos/imu_test/`, `throttle_serial/`)는 이 스키마로 안 찍고 있다** —
  통합 펌웨어(마스터 설계도 §8.1) 작성 시점에 `Serial.print()` 포맷을 이 표에 맞추는 작업이 필요하다.
  **이건 이 문서가 아니라 펌웨어 통합 작업의 할 일 목록에 들어간다** — 여기서는 "받을 형식"만 못박아둔다.
- sim 쪽(`sim/sim_stage1/`)도 학습 에피소드를 이 컬럼명으로 export하는 유틸이 하나 필요하다
  (`mode=RL`, `servo1..4`는 `hopper_aviary.py`의 `a1..a4`를 그대로, `throttle`도 동일 — 이미 5차원
  액션 구조가 이 스키마와 거의 1:1이라 변환이 쉽다).

---

## 5. 3D 오브젝트 — 무엇을 어떻게 렌더링하나

### 5.1 형상 — 처음부터 실제 CAD를 쓰지 않는다

- **Stage 1(지금 시작)**: 프리미티브 조합 — 원통(EDF 하우징) + 링(베인링) + 얇은 박스 4개(베인, 90°
  간격) + 가는 실린더 4개(다리). 비율은 `cad/hopper_params.scad`의 `edf_housing_od`·`vane_ring_od`·
  `foot_circle` 등 기존 상수를 그대로 가져다 쓰면 실제 기체 비율과 맞는다 — **새로 재는 게 아니라
  이미 정해진 숫자를 옮기기만 하면 됨.**
- **Stage 2(여유되면)**: `cad/print_parts/*.stl`(§9-0 export 파이프라인이 이미 있음, `cad/print_parts/README.md`)을
  Three.js `STLLoader`로 그대로 불러오기. CAD가 갱신되면 3D 뷰어도 자동으로 최신 형상이 된다.
  **선행조건**: STL이 실제로 export돼 있어야 함(2026-09-17 기준 아직 안 됨, `cad/README.md` 참고) — 그
  전엔 Stage 1 프리미티브로 충분하다.

### 5.2 자세 매핑

- BNO085가 **쿼터니언을 직접 출력**한다(마스터 설계도 §6.5) — 오일러각으로 변환했다가 다시 3D 회전에
  쓰면 짐벌락 근처에서 오차가 생긴다. **가능하면 CSV에 쿼터니언 4개(`qw,qx,qy,qz`)를 원값으로 같이
  찍어서, 3D 뷰어는 그걸 Three.js `Quaternion`에 직접 대입**하는 쪽을 권장(§4 표에 옵션 컬럼으로 추가
  가능). 오일러각(φ,θ,ψ)은 차트(산출물 A)용으로는 그대로 유용하니 둘 다 찍어도 된다.
- 좌표계는 `01-avionics-integration-final.md` §1의 방위 규약(+X=FWD/0°, +Y=LEFT/90°...)을 그대로 따른다
  — Three.js 좌표계(Y-up)와 축이 다르므로 **한 번만 변환 함수를 만들어두면 나머지는 신경 안 써도 됨**.

### 5.3 베인 애니메이션

- `servo1..4` 값을 베인 박스의 회전각으로 매핑 — 이것도 TC-1(베인 방향 검증) 디버깅에 바로 쓸모 있다
  (부호가 반대면 3D 뷰어에서 바로 티가 남).

---

## 6. 단계별 개발 로드맵 (소프트웨어팀 웹 서브트랙)

RL 서브트랙(`sim/`)과 **병렬로, 실측 데이터를 기다리지 않고 지금 바로 착수 가능**하다는 게 핵심 — 실제
주차 배치는 [`semester-roadmap.md`](../execution/semester-roadmap.md)에 있다. 여기서는 이 트랙 자체의
단계만 정의:

| Phase | 할 일 | 선행조건 |
|---|---|---|
| **W-A 뼈대** | Vite 프로젝트 세팅, Three.js로 프리미티브 호퍼 형상 띄우기, 가짜(합성) CSV로 회전 애니메이션 동작 확인 | 없음 — **지금 바로 시작 가능** |
| **W-B 차트** | Chart.js/Recharts로 시계열 그래프 뼈대, 가짜 데이터로 PID vs RL 두 시리즈 겹쳐 그리기 | W-A와 병렬 가능 |
| **W-C 실데이터 연결** | §4 스키마 확정 → 실제 CSV 파서로 교체(TC-0/TC-1 로그로 첫 검증) | 실험 A/B/C 데이터 존재 (기구·전자·실험팀 산출물) |
| **W-D 지표 계산** | 복원시간·오버슈트·정상상태오차를 코드로 자동 계산(사람이 눈으로 재지 않게) | TC-3 데이터 |
| **W-E 비교 완성** | TC-3(PID) vs TC-5(RL) 나란히, 요약 테이블 + 발표용 내보내기(PNG/PDF export) | TC-5 데이터, 이게 발표 핵심 자료 |
| **W-F (스트레치)** | 라이브 모드(WebSocket), STL 실형상 교체 | ESP32 텔레메트리, STL export 완료 |

---

## 7. 기술 스택 추천

| 레이어 | 추천 | 이유 |
|---|---|---|
| 빌드 도구 | **Vite** | 설정 거의 없이 바로 시작, HMR 빨라서 동아리 세션 중 실습에 적합 |
| 언어 | **JavaScript(또는 TypeScript)** | 3D/차트 라이브러리 생태계가 압도적으로 JS 쪽. TS는 팀이 타입에 익숙하면 버그를 미리 잡아줌(선택) |
| UI 프레임워크 | **바닐라 JS로 시작 → 필요하면 React 추가** | 팀 대부분이 Python(RL) 경험은 있어도 React 경험은 없을 수 있음. 화면이 3개뿐이라 처음엔 프레임워크 없이도 충분 — 나중에 상태 관리가 꼬이기 시작하면 그때 React 도입(과설계 방지) |
| 3D | **Three.js** | 압도적 1위 생태계, 한국어 튜토리얼도 많음. `OrbitControls`(마우스로 시점 회전)·`STLLoader`(§5.1) 내장 |
| 차트 | **Chart.js** (또는 Recharts, React 쓰면) | 시계열 겹쳐그리기·줌 플러그인 있음, 설정 간단 |
| CSV 파싱 | **PapaParse** | 헤더 자동 인식, 대용량도 스트리밍 파싱 가능 |
| 배포 | **GitHub Pages(정적)** | 저장소가 이미 GitHub — 별도 서버 없이 `main` 브랜치에서 바로 배포 가능(Stage 1 한정) |

이 조합의 공통점: **전부 무료·설정 최소·튜토리얼 풍부** — 동아리 세션 시간(1~3시간)에 실습으로 소화
가능한 난이도로 고른 것. React/백엔드가 필요해지는 시점은 §6 W-F 이후로 미뤄둔다.

---

## 8. 아직 안 정한 것

| 항목 | 필요 정보 | 언제 |
|---|---|---|
| CSV에 쿼터니언 원값을 넣을지, 오일러각만 쓸지(§5.2) | 펌웨어 통합 시점 결정 | 통합 펌웨어 작성 시 |
| 백엔드가 실제로 필요해지는 시점(§3, §6 W-F) | ESP32 WiFi 텔레메트리 착수 여부 | STAGE 2 |
| React 도입 여부(§7) | 팀 규모·화면 복잡도 늘어나는 정도 | W-D 이후 판단 |
| 배포 방식 — GitHub Pages vs 학교 로컬 서버 | 발표 당일 네트워크 환경 | 발표 준비 주차 |
| STL 실형상 전환 시점(§5.1 Stage 2) | `cad/print_parts/` STL export 완료 여부 | CAD 트랙과 연동 |

---

## 9. 관련 문서

| 문서 | 관계 |
|---|---|
| [`00-hopper-master-design.md`](00-hopper-master-design.md) §9·§11 | 이 문서가 보여주는 데이터의 출처(RL 인터페이스 스펙, 시험카드) |
| [`01-avionics-integration-final.md`](01-avionics-integration-final.md) §3.5 | 로그 파일명 규칙, USB 시리얼 로깅 확정 사항 |
| [`../../sim/README.md`](../../sim/README.md) | RL 학습 트랙 — 산출물 C(§2)의 데이터 출처 |
| [`../execution/semester-roadmap.md`](../execution/semester-roadmap.md) | 이 문서의 §6 로드맵이 전체 학기 세션에서 실제로 언제 배치되는지 |

---
*신규 문서 — 다음 갱신은 §4 스키마가 펌웨어 통합 코드에 실제로 반영된 시점, 또는 W-A 뼈대 착수 후
기술 선택이 바뀌면.*

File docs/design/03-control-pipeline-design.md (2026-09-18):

# 제어 파이프라인 심화 설계 — PID·RL 아키텍처, 3D 시뮬레이션, 온보드 이식

COSMOS PRJ-01. **이 문서가 "PID/RL 제어를 정확히 어떻게 만들고 어떻게 실기에 올리는가"의 단일 진실
소스다.** `sim/sim_stage1/`(현재 구현)이 최종 목표가 아니라 **파이프라인이 도는지 확인하는 PoC**라는
점, 그리고 그 다음 단계(3D 물리엔진 전환·아키텍처 선택·온보드 배포)가 여태 문서화가 안 돼 있었다 —
이 문서가 그 공백이다.

**이 문서가 생긴 이유(2026-09-18)**: 부장이 "이 프로젝트는 이미 대학급 수준이니 PID·RL도 수준급으로
만들 생각"이라며 심화 리서치(§7의 출처)를 제공, `sim_stage1`을 최종 답이 아니라 테스트 단계로 재정의.
아래는 그 리서치를 **직접 검증하고**(§7에 검증 상태 표시) COSMOS 기체에 맞게 구조화한 것.

> **튜토리얼이 아니다.** "어떻게 설치하고 어떻게 코딩하는지"는 여기 없다 — 그건 다음 단계(부장 표현:
> "일단 튜토리얼 만드는 건 재껴두고"). 이 문서는 **뭘 선택하고 왜, 뭘 아직 검증 안 했고 누가 언제
> 검증할지**를 정하는 설계도다. 소프트웨어팀 차장이 이 문서를 읽고 §8(팀 행동항목)부터 시작하면 된다.

---

## 0. 이 문서가 대체·흡수하는 것 (중복 제거)

같은 얘기가 여러 파일에 흩어져 있던 걸 여기 하나로 모았다. 아래 파일들은 이제 **이 문서로 링크만**
걸고, 본문은 각자 원래 역할만 남긴다.

| 기존 위치 | 있던 내용 | 처리 |
|---|---|---|
| `AGENTS.md` "PID vs RL 비교 실험 프로토콜" | 비교 철학 4문단 | 원칙 한 문단만 남기고 상세는 이 문서 §3으로 이동 |
| `00-hopper-master-design.md` §9 | obs(12)/act(4) 스펙 — **rev B 잔재라 실제 코드(6/5차원)와 이미 어긋나 있었음** | 이 표 삭제, 이 문서 §4로 대체(정확한 스펙 + Stage별 구분) |
| `sim/README.md` | Stage 1을 "구현 완료"로만 서술, 최종 목표처럼 읽힘 | "PoC, 최종 아님" 한 줄 추가 + 이 문서로 링크 |
| `docs/design/02-web-dashboard-design.md` §2 산출물 C | RL 시뮬 3D와 웹뷰어 3D의 경계가 흐릿했음 | §2.1(아래)에서 명확히 구분 |

---

## 1. 목표 재확인

- **Stage 1(`sim/sim_stage1/hopper_aviary.py`, 완료)은 파이프라인 검증용 PoC다.** numpy로 직접 적분한
  단순화 모델 — 실제 물리 신뢰도가 낮고(공력 lumped 근사, 서보 동특성 없음, 충돌·접촉 없음), 목적은
  "SB3·gymnasium 연동이 우리 기체 상태/액션 구조로 정상 동작하는가"였을 뿐이다. **이 자체를 최종 학습
  결과로 쓰지 않는다** — 이미 `sim/README.md`·`hopper_aviary.py` 주석에도 명시돼 있던 원칙을 여기서
  다시 못박는다.
- **진짜 목표**: 실물 CAD/치수를 반영한 **3D 강체 물리엔진** 기반 시뮬레이션에서 학습하고, 학습된
  정책을 실제 온보드 비행 컴퓨터(Teensy 4.0)에 이식해서 baseline(PID/LQR)과 정량 비교한다 — 이게
  `AGENTS.md`가 원래부터 약속한 것과 같은 목표이되, **더 깊은 리서치·검증을 거쳐 실행**한다.
- 3D는 두 군데서 쓰인다 — **혼동하지 말 것**:

### 1.1 두 개의 "3D" — RL 훈련용 물리엔진 vs 웹 뷰어

| | RL 훈련용 3D 물리엔진 (이 문서) | 웹 3D 뷰어 (`02-web-dashboard-design.md`) |
|---|---|---|
| 역할 | **물리를 계산**한다(충돌·강체동역학·공력) — RL이 학습하는 대상 | 이미 계산된 로그(CSV)를 **그대로 재생**한다 — 물리 연산 없음 |
| 언제 쓰나 | 학습 중(팀 PC에서, 보통 GUI 없이 헤드리스로 수백만 스텝) | 시험 후/발표 시 결과를 보여줄 때 |
| 기술 | Python + PyBullet(또는 그 위 프레임워크, §2) | JavaScript + Three.js |
| 입력 | RL 액션 → 물리엔진이 다음 상태 계산 | CSV의 이미 기록된 자세값 → 그대로 회전만 |
| 공유 자산 | **같은 3D 모델(URDF/mesh)을 재사용 가능** — `cad/print_parts/*.stl`을 URDF가 감싸는 것과 Three.js가 불러오는 것, 소스 메쉬가 같다 | 위와 동일 |

**한 줄 규칙**: 물리 계산이 필요하면 이 문서(§2)의 시뮬레이터, 그냥 보여주기만 하면 `02번 문서`의
웹 뷰어. 3D 모델 파일은 CAD 트랙이 한 번만 만들면 양쪽에서 재사용한다.

---

## 2. 시뮬레이션 스테이지 로드맵 (재정의)

### Stage 1 — numpy 커스텀 env (완료, PoC로 유지)

- `sim/sim_stage1/hopper_aviary.py`. **버리지 않는다** — 물리엔진보다 100~1000배 빠르고 의존성이
  없어서, 알고리즘/보상함수 아이디어를 빠르게 스모크테스트하는 용도로 Stage 2 이후에도 계속 쓸모 있다
  (예: "이 보상항이 방향이 맞나"를 3D 엔진 돌리기 전에 여기서 먼저 확인).

### Stage 2 — 3D 물리엔진 전환 (신규 목표, 착수 전)

**후보 비교** — `AGENTS.md`가 2026-09-14에 gym-pybullet-drones를 이미 한 번 검토·기각했다(이유: 모터
4개 대칭배치 믹싱 공식이 `_physics()`/`_dynamics()`에 하드코딩돼 있어 모터1+베인4 구조를 넣으려면
포크 수준 수정 필요, 소스코드 직접 확인 후 판단). **이번에도 같은 기준(소스 직접 확인)으로 재검토했다.**

| 후보 | 물리엔진 | 검증 상태(2026-09-18) | 판단 |
|---|---|---|---|
| **PyFlyt** (`jjshoots/PyFlyt`) | PyBullet | **문서 확인함(WebFetch로 공식 문서 읽음), 소스코드 레벨 검증은 아직** — `Motors`·`Gimbals`(짐벌/TVC)·`LiftingSurfaces`(공력면, 베인에 대응 가능)를 **모듈로 조합**해 "임의 구성의 UAV"를 만드는 구조라고 문서에 명시돼 있음(biplane·quadcopter·rocket 등). 내장 `Rocket` 드론 타입도 있음. | **가장 유망한 1순위 후보** — gym-pybullet-drones가 기각된 이유(하드코딩된 대칭 믹싱)가 여기엔 없어 보임(모듈형이라). **단, "보여 보인다"와 "실제로 된다"는 다르다 — §8 행동항목대로 팀이 `PyFlyt/core/drones/` 소스를 직접 읽고 EDF 1개+베인4 구성이 정말 포크 없이 되는지 확인 후 확정할 것.** |
| **gym-pybullet-drones** | PyBullet | 기각 유지(2026-09-14 검토, `AGENTS.md` 참고) | 재검토 안 함 — PyFlyt가 이미 이 문제를 모듈화로 풀어놓은 것으로 보여서 우선순위 낮음 |
| **커스텀 PyBullet + URDF 직접 구현** | PyBullet(raw) | 검증 불필요(우리가 직접 짜는 것) | PyFlyt가 막히면(§8) 이게 폴백 — PyBullet은 저수준 API가 자유로워서 "모터1+베인4"를 처음부터 우리 식대로 짤 수 있음. 단, 접촉·공력·모터 동역학을 전부 손으로 구현해야 해서 개발 비용 가장 큼 |

**CAD→물리엔진 자산 경로(이미 있는 파이프라인 재사용)**:
```
cad/hopper_params.scad(OpenSCAD, 정본)
   → STL export(cad/print_parts/, 이미 있는 워크플로 — cad/print_parts/README.md)
   → URDF 작성(STL을 <mesh>로 감싸고 <inertial>에 sim/sim_stage1/params.yaml의 mass/Jxx/Jyy/Jzz를 그대로 기입)
   → PyBullet이 URDF를 로드
```
**새 CAD 도구가 필요한 게 아니다** — 이미 확정된 `hopper_params.scad`와 실측 질량속성을 XML 한 겹으로
감싸는 작업이다. STL export가 아직 안 된 상태(`cad/README.md` 참고)이므로 **Stage 2 착수의 실질적
선행조건은 STL export 완료**.

### Stage 3 — Sim-to-Real

- Stage 2에서 학습한 정책을 §6(온보드 배포)으로 실기에 올리고, `00-hopper-master-design.md` §11
  시험카드(TC-3~TC-5)로 baseline과 비교. 이 단계 자체는 기존 계획과 동일 — 새로울 것 없음.

---

## 3. 제어 아키텍처 — 직접비교(Swap) vs Residual RL

두 가지 서로 다른 질문에 서로 다른 구조가 맞는다. **섞어서 생각하면 안 된다.**

| | 직접비교(Swap) — 현재 `AGENTS.md` 프로토콜 | Residual RL — 리서치가 제안한 구조 |
|---|---|---|
| 질문 | "PID가 나은가 RL이 나은가?" (발표에서 이미 약속한 핵심 질문) | "실기에서 안전하게, 성능을 더 짜낼 수 있는가?" |
| 구조 | 제어 블록을 **통째로 교체** — 한 런은 순수 PID, 다른 런은 순수 RL 정책 | `output = PID_output + RL_Δ` — RL은 PID가 이미 만든 출력 위에 **보정치만** 더함 |
| 장점 | 결과가 "PID vs RL" 프레이밍과 정확히 일치, 발표 스토리 그대로 씀, 구현 단순 | RL이 발산해도 PID가 베이스를 잡고 있어 더 안전, sim-to-real 격차에 강함(RL이 배워야 할 몫이 작음) |
| 단점 | RL이 처음부터 전부 배워야 해서 sim-to-real 격차에 더 취약 | "AI가 사람보다 나은가"라는 원래 질문과 프레이밍이 어긋남(RL 단독 성능을 안 보여줌) |
| **권장** | **Phase A(우선)** — 학기 핵심 산출물은 이거다. `semester-roadmap.md` Week 7–8이 이 구조 기준 | **Phase B(여유 시 확장)** — Phase A 완료 후, "그럼 더 안전한 실전 버전은?"이라는 후속 질문으로 붙이면 발표에서 오히려 깊이를 더해줌 |

**결론**: 지금 로드맵(`semester-roadmap.md`)은 안 바꾼다 — Phase A(직접비교)가 기본 경로. Residual RL은
Week 9(여유 주차)의 확장 옵션으로 `semester-roadmap.md` §3 Week 9 표에 추가해뒀다.

---

## 4. State / Action Space — 스테이지별로 다르다

`00-hopper-master-design.md` §9의 낡은 12차원/4차원 표(rev B 잔재, 실제 코드와 이미 안 맞았음)는
**폐기하고 이 표가 정본이다.**

### Stage 1 (구속, 자세만) — 이미 구현된 그대로, 안 바뀜

```
관측 obs (6): [phi, theta, psi, wx, wy, wz]      — 자세각 + 바디 각속도
행동 act (5): [a1, a2, a3, a4, throttle]          — 베인4 + 스로틀
```
위치를 안 재는 이유: 만능조인트로 구속돼 있어 위치가 상수다(재도 정보량이 0). 이 스펙은 그대로 유지.

### Stage 2/3 (자유비행, 위치·속도 포함) — 리서치 제안 채택

```
상태 S = [px,py,pz, vx,vy,vz, qw,qx,qy,qz, wx,wy,wz, θ_vane1..4]   (16차원)
행동 A = [Δα1,Δα2,Δα3,Δα4, T_throttle]                              (5차원, Residual RL이면 Δ, 직접비교면 절대값)
```

- 쿼터니언(qw,qx,qy,qz)을 쓰는 이유: 오일러각은 짐벌락(θ=±90°) 특이점이 있음 — Stage 1은 소각도
  근처만 다뤄서 문제없었지만, Stage 2/3는 큰 자세 변화를 다룰 수 있어 쿼터니언이 안전하다.
- **위치·속도(px,py,pz,vx,vy,vz)는 STAGE 3+ 센서(VL53L1X ToF + PMW3901 광류, BOM B7/B8)가 붙어야
  실기에서 측정 가능** — `00-hopper-master-design.md` BOM 계획과 이미 맞물려 있다. Stage 2 시뮬레이션
  자체는 (센서 없이) 물리엔진이 위치를 그냥 알려주므로 먼저 진행 가능, **실기 이식은 그 센서가 붙은
  뒤에나 의미 있다** — 순서를 착각하지 말 것.
- 베인 현재각(θ_vane1..4)을 상태에 포함하는 이유: 서보에 지연(§5)이 있어서, "명령한 각도"와 "실제
  각도"가 다를 수 있다 — 정책이 그 차이를 알아야 더 정확히 제어할 수 있다.

---

## 5. Domain Randomization — 현재 구현과의 갭

`sim/sim_stage1/params.yaml`의 `domain_rand` 블록(현재값)과 리서치 제안값을 대조한 표. **이미
`00-hopper-master-design.md` §9 rev B 표에 "서보지연 20~60ms"가 언급돼 있었는데, 실제로 코드에 구현된
적이 없다** — 발견한 갭이라 여기 기록해둔다.

| 파라미터 | 현재(`params.yaml`) | 리서치 제안 | 반영 상태 | 비고 |
|---|---|---|---|---|
| 질량·관성(Jxx/Jyy/Jzz) | ±30% | — | 구현됨 | 유지 |
| 베인 모멘트암 | ±15% | — | 구현됨 | 유지 |
| 추력계수 Kf | ±20% | — | 구현됨 | 유지 |
| **CG 오프셋** | **±3mm** | **±5~15mm** | 구현은 됐으나 **범위가 리서치 제안보다 좁음** | 조립 공차를 실측(§8-4, `01-avionics-integration-final.md` §8.2)한 뒤 그 실측 오차 범위로 다시 정할 것 — 지금 3mm는 근거 없는 임시값 |
| **서보 반응 지연** | **미구현** | **20~60ms** | **갭 — Stage 2에서 반드시 추가** | 액추에이터 동특성 자체가 `hopper_aviary.py`에 없음(명령 즉시 반영). 물리엔진 전환(§2) 시 1차 지연 필터로 추가 |
| **바람 외란/돌풍** | 미구현 | 무작위 외란 토크 | STAGE 1(구속)엔 불필요, STAGE 2/3(자유비행)에 필요 | 구속 시험은 실내·저속이라 우선순위 낮음 — Stage 2 물리엔진 전환 시 검토 |
| **추력 감쇄(배터리 전압강하)** | 미구현 | 배터리 전압에 따른 추력 저하 | 권장 추가 | `01-avionics-integration-final.md` §3.2 전류예산과 연동 가능(전압 새그 실측치 있으면 그대로 반영) |

---

## 6. 온보드 배포 경로 (Sim-to-Real 이식)

`00-hopper-master-design.md` §8.1-7("`control_hover()`의 `output = K * error;` 한 줄을 정책망 추론
호출로 교체")이 **어떻게** 되는지를 여기서 구체화한다.

### 6.1 경로 두 가지

| 경로 | 방법 | 장점 | 단점 |
|---|---|---|---|
| **A. ONNX → TFLite Micro** | PyTorch/SB3로 학습한 PPO Actor를 ONNX export → TFLite Micro 런타임으로 Teensy에서 추론 | 표준 툴체인, 모델 구조 바뀌어도 재작업 적음 | TFLite Micro 라이브러리 의존성 추가, 빌드 복잡도 ↑ |
| **B. 수동 C++ 행렬곱** | 학습된 가중치(작은 MLP, 예: 은닉층 2개×64노드)를 배열로 export → Teensy에서 직접 forward pass(행렬곱 몇 줄) | **의존성 없음**, 코드가 30~50줄 수준, 디버깅 쉬움 | 모델 구조 바뀔 때마다 손으로 다시 export |

**조사 결과(2026-09-18, WebSearch로 확인)**: TFLite Micro는 Teensy 4.0에서 커뮤니티 예제로 이미
동작 확인됨(MNIST 추론 등), 작은 MLP 기준 서브-밀리초(1ms 미만) 추론이 보고됨. 우리 정책망은 그보다도
훨씬 작을 가능성이 높아(관측 6~16차원, 행동 5차원) **경로 B(수동 구현)도 충분히 현실적** — 오히려
학생 팀에게는 "왜 이게 동작하는지 눈으로 보이는" 경로 B가 디버깅·이해 측면에서 유리할 수 있다.
**권장: 경로 B를 먼저 시도, 안 풀리면 경로 A로.**

### 6.2 제어 루프 주기

작은 MLP는 10~50µs 수준 추론이 가능하다는 근거가 있어(§7 원 리서치 + 위 조사), Teensy 4.0(600MHz)
기준 **100Hz 이상 제어 루프**가 무리 없이 나온다 — 스톡 SolidGeek 코드의 제어 루프 주기와 비교해
병목이 안 됨을 확인할 것(`firmware/reference/SingleRotorUAV/src/control.cpp` 루프 주기 실측, Stage 3
착수 시).

---

## 7. 참고 오픈소스 — 검증 상태 명시

부장이 제공한 리서치 목록을 **직접 확인(WebFetch/WebSearch)한 결과**. "검증상태" 컬럼이 이 문서의
신뢰도를 결정하는 부분이니 꼭 읽을 것 — 링크만 보고 적어놓은 게 아니라 실제로 열어봤다.

| 프로젝트 | 용도 | 검증 상태 | 가져올 것 | 주의점 |
|---|---|---|---|---|
| [`jjshoots/PyFlyt`](https://github.com/jjshoots/PyFlyt) | Stage 2 물리엔진 1순위 후보 | 공식 문서 확인함(§2 표) | `Motors`/`Gimbals`/`LiftingSurfaces` 모듈 조합, 내장 `Rocket` 드론, Gymnasium 표준 API | **소스코드(`PyFlyt/core/drones/`) 직접 확인 전까지 미확정** — §8 행동항목 |
| `utiasDSL/gym-pybullet-drones` | (기각됨) | 2026-09-14 소스 직접 확인 완료(`AGENTS.md`) | — | 재검토 안 함, PyFlyt로 대체 검토 중 |
| [`alxndrTL/Landing-Starships`](https://github.com/alxndrTL/Landing-Starships) | 랜딩 RL 참고 | 검색 확인함 — **Unity ML-Agents(C#) 기반, 우리 Python/PyBullet 스택과 안 맞음** | 보상함수 설계 아이디어만(코드 재사용 불가) | 3D 물리엔진 후보에서 제외 — 개념 참고용으로만 |
| [`ibiscp/Rocket-Lander`](https://github.com/ibiscp/Rocket-Lander) | 랜딩 RL 참고 | 확인함 — **2D Box2D 게임(OpenAI Gym LunarLander 계열), 3D 아님** | 상태공간·보상함수 설계 패턴(속도·거리·각도·연료·접지 항) | 원 리서치가 "VTVL Hopper 3D"로 분류했는데 **정정 — 이건 3D가 아니다**, 물리엔진 후보 아님 |
| [`TVC-Hopper/tvc-hopper`](https://github.com/TVC-Hopper/tvc-hopper) | 비행소프트웨어 아키텍처 | 확인함 — SPP 프로토콜 기반 텔레메트리(호스트/서버/뷰어 3계층), MATLAB 시각화 | FSM(상태머신) 설계 패턴, 텔레메트리 계층 구조 아이디어 | 서버가 Raspberry Pi 전제 — 우리는 ESP32라 그대로 이식은 안 되고 **구조만** 참고 |
| `tomkuttler/TVC-Rocket-Flight-Code` | Teensy 서보 제어 초기 참고 | 원 리서치 그대로(직접 재확인 안 함) | 서보 각도 리미터·데드밴드 처리 패턴 | 2축 짐벌 대상 코드 — 우리는 베인4라 믹서 구조는 다름, 리미터 패턴만 |
| **[`UrosKukovic/TVC_Self_Landing_Rocket`](https://github.com/UrosKukovic/TVC_Self_Landing_Rocket)** *(이번에 새로 발견)* | **STAGE 3(위치제어) 설계 최우선 참고** | 상세 확인함(WebFetch 2회) | 90mm EDF 단일모터 + **실제 비행 성공**(호버→강하→소프트랜딩, 착지속도 50~100mm/s). **센서스택이 우리 BOM과 사실상 동일**: BNO085 IMU + ToF(우리는 VL53L1X, 이쪽은 TeraRanger) + **PMW3901 광류(BOM B8과 정확히 일치)**. 캐스케이드 PID(내부 자세루프 + 외부 고도·수평속도루프) + 2D 칼만필터. STM32F411(100Hz) + ESP32-S3 센서허브 | 착지속도 벤치마크 수치, 캐스케이드 제어 구조, 칼만필터 융합 방식 | **액추에이션이 다르다** — 이쪽은 노즐이 통째로 기우는 2축 짐벌(서보4개, push-pull 링키지)이지, 우리처럼 고정 EDF+배기 베인4 방식이 아니다. 믹서·CAD는 못 가져옴, **제어/센서 아키텍처만** 가져올 것. **라이선스 CC BY-NC**(비영리) — 교육용 참고는 문제없으나 코드를 그대로 베끼면 출처 표기 필요 |

---

## 8. 팀 행동항목 (아직 안 정한 것 — 이 문서가 대신 결정하지 않음)

| # | 항목 | 누가 | 언제 |
|---|---|---|---|
| 1 | **PyFlyt 소스코드(`PyFlyt/core/drones/`, `PyFlyt/core/abstractions/`) 직접 읽고 EDF1+베인4 구성이 포크 없이 되는지 확인** — 안 되면 §2의 "커스텀 PyBullet+URDF" 폴백으로 | 소프트웨어팀(RL 담당) | Stage 2 착수 전(`semester-roadmap.md` 상 여유 있을 때, 늦어도 baseline 확정 전) |
| 2 | CAD→URDF 변환 실제 작성 — `cad/print_parts/` STL export 완료가 선행조건 | 소프트웨어팀 + 기구팀 연결 | STL export 완료 후 |
| 3 | Residual RL(§3 Phase B) 착수 여부 | 부장 + 소프트웨어팀 | Phase A(직접비교) 완료 후, 여유 시간 보고 |
| 4 | 온보드 배포 경로 A(TFLite Micro) vs B(수동 C++) 확정 | 소프트웨어팀(펌웨어 연동 담당) | 학습된 정책이 처음 나온 뒤 |
| 5 | CG 오프셋 도메인랜덤화 범위(§5) — 실측 조립오차로 갱신 | 기구팀 실측 → 소프트웨어팀 반영 | 조립 후(`01-avionics-integration-final.md` §8.2 CG 측정과 동시) |
| 6 | 서보 반응지연 실측 — 20~60ms가 우리 MG90S 직결구동에도 맞는 범위인지 확인 | 기구·전자팀(TC-2) | TC-2(베인 힌지모멘트 실측) 시 같이 측정 |

---

## 9. 관련 문서

| 문서 | 관계 |
|---|---|
| [`00-hopper-master-design.md`](00-hopper-master-design.md) §8·§11 | RL 이식 지점(§8.1-7), 시험카드(TC-3~5) — 이 문서 §6·§3이 그 지점의 구체 구현 |
| [`02-web-dashboard-design.md`](02-web-dashboard-design.md) §1.1 | 이 문서 §1.1과 대응 — "두 개의 3D" 경계 정의는 양쪽 문서에 같은 표로 들어있음(의도적 — 어느 쪽을 먼저 읽어도 헷갈리지 않게) |
| [`../../sim/README.md`](../../sim/README.md) | Stage 1(PoC) 구현 상세 — 이 문서 §2가 그다음 단계 |
| [`../../sim/sim_stage1/params.yaml`](../../sim/sim_stage1/params.yaml) | §5 갭 분석의 대상 파일 |
| [`../execution/semester-roadmap.md`](../execution/semester-roadmap.md) | 이 문서의 §2·§3 방향이 실제 주차에 어떻게 배치되는지(RL 트랙 확장에 따른 일정 영향은 그 문서 §0.2 참고) |

---
*신규 문서 — 다음 갱신은 §8-1(PyFlyt 소스 검증) 결과가 나온 시점, 또는 Stage 2 물리엔진이 실제로
확정된 시점.*

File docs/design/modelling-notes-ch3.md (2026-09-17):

# 논문 3장(Modelling) 정리 — 운동방정식·베인 공력식

원문: Jacobsen, E.B. *Modelling and Control of Thrust Vectoring Mono-copter*, Aalborg University, 2021,
Chapter 3 "Modelling" (원문 18–33쪽 / PDF 24–39쪽) — `docs/design/references/Jacobsen2021_*.pdf`.

**목적**: 이 장의 수식을 `sim/sim_stage1/hopper_aviary.py`가 그대로 코드화했다. 이 문서는 그 대응관계를
명시하고, 코드가 논문과 어디서 일부러(또는 실수로) 다른지 기록해둔다 — **params.yaml 값을 실측치로
교체할 때 반드시 다시 볼 것.**

> ⚠️ 이 문서는 2026-09-17에 (재)작성됐다. 원래 같은 이름으로 존재했다고 기록돼 있었으나 실제 파일은
> 어디에도 없었다(Codex 세션 안에서만 만들어지고 export가 안 된 것으로 추정) — 이번에 논문 PDF에서
> 다시 추출해 새로 썼다.

---

## 1. 좌표계 (§3.1)

- **월드 프레임 W**: 관성 고정 좌표계(flat earth).
- **바디 프레임 B**: 기체 무게중심(COM)에 고정, 같이 움직임. **xb·yb축이 베인과 나란히, zb축이
  모터 회전축(=배기 방향)과 나란**하도록 잡음 — 우리 좌표계(설계도 §4, "Z=0 배기면, +Z 위")와
  같은 관례.
- **자세**: Tait-Bryan 각 η=[φ,θ,ψ](roll,pitch,yaw), **ZYX 순서** 회전행렬 R^w_b(ψ,θ,φ) (식 3.2–3.3).
- **바디 각속도 ω_B ↔ 오일러각 변화율 η̇**: 변환행렬 W_η (식 3.4–3.5). **θ=±90°에서 특이점** —
  코드(`hopper_aviary.py`)도 `cos_theta`를 `max(abs(cos_theta), 1e-3)`로 클리핑해서 방어(논문은
  "정상 운용 범위 밖이라 안 다룸"이라고만 하고 넘어감 — 우리 코드가 더 방어적).
- **관성행렬 대각 가정** (식 3.7): 질량이 로컬 축 기준 고르게 분포하면 비대각항(product of inertia)이
  0에 가까워짐 — 논문은 CAD 질량속성 계산으로 검증했다고 함. **우리도 나중에 Onshape/CAD 질량속성으로
  이 가정이 맞는지 확인 필요** (지금은 Jxx=Jyy≈같은 값으로 대칭 가정만 하고 있음, params.yaml 주석 참고).

## 2. 힘·모멘트 구성 (§3.2)

3차원 자유물체도(Fig 3.2): 추력 Ft(모터) + 베인 제어력 F1..F4 + 베인 항력 Fd1..Fd4 + 중력.
**공력(동체 자체의 양력·항력)은 호버 근처에서 무시** — 우리도 동일 가정.

### 2.1 추진력 모델 (§3.2.1)

```
모터 1차계:  ωt(s)/ut(s) = Kt / (τt·s + 1)      (τt = 0.0345s, "충분히 빠름"이라 무시 가능)
추력:        Ft = Kf · ωt²                        (식 3.9)
```

→ 코드 대응: `params.yaml`의 `Kf`. 단, **코드는 실제 RPM(ωt) 대신 `omega_t_equiv = throttle*3000`
(throttle 기반 임시 스케일)을 씀** — 논문처럼 진짜 각속도가 아니다. **실험 A(EDF 추력곡선) 이후엔
DShot에서 읽은 실제 RPM으로 교체해야 논문 식 그대로가 됨.** 모터 1차계(시상수 τt)는 지금 코드에
아예 없음 — Stage 1 목표(파이프라인 검증)엔 불필요하다고 판단해 생략된 것으로 보임, 실기 이식 전엔
넣을지 검토.

### 2.2 베인 공력 모델 (§3.2.2) — ⚠️ 코드와 논문이 다른 지점

베인은 "대칭 날개(에어포일)"로 취급, 양력(제어력)·항력(손실) 표준식:

```
F_lift = ½ρv²·Cl·A_fin        (3.11)
F_drag = ½ρv²·Cd·A_fin        (3.12)
```

Cl·Cd를 각도 α의 함수로: 대칭 익형이라 ±10° 이내에서 **선형 근사**(Fig 3.6, XFoil 시뮬레이션값 회귀):

```
Cl(α) = CLα·α     Cd(α) = CD0     (식 3.13–3.14)
CLα = 0.008905, CD0 = 0.001054   ← 논문 저자의 "실제 베인" XFoil 회귀값. 우리 베인(25×45×2.5mm)
                                    형상이 다르므로 그대로 쓰면 안 됨 — params.yaml에 이미 PLACEHOLDER로 표시됨
```

**공기 속도 v는 직접 못 재니, 추력 Ft에서 역산** (배기 단면적 A_duct 가정, 식 3.15):

```
v² = Ft / (A_duct·ρ)
```

이걸 대입해서 **최종적으로 베인력을 "모터 추력 Ft에 비례하는 형태"로 정리**(식 3.16–3.17):

```
F_n  = Ft · [ CLα·A_fin / (2·A_duct) ] · α_n   =  Ft · CL · α_n     ← CL은 "뭉쳐진" 상수 (lumped)
F_dn = Ft · [ CD0·A_fin / (2·A_duct) ]          =  Ft · CD
```

**⚠️ 코드 확인 결과 (2026-09-17)**: `hopper_aviary.py`의
```python
F1, F2, F3, F4 = self.CLalpha * Ft * alpha
```
는 `params.yaml`의 `CLalpha`(=논문의 raw `CLα`, 즉 A_fin/A_duct 기하 비율이 **안 곱해진** 값)를
마치 식 3.16의 **뭉쳐진 CL**(=`CLα·A_fin/(2·A_duct)`)인 것처럼 그대로 쓰고 있다. 즉 코드에
`A_fin/(2·A_duct)` 기하 인자가 아예 빠져 있다.

**지금 당장은 문제 없음** — 값 자체가 전부 PLACEHOLDER라 절대 크기가 의미 없고, Stage 1의 목표는
"파이프라인이 도는가"만 확인하는 것이기 때문. **하지만 실험 A 이후 값을 채울 때 둘 중 하나로 명확히
할 것**:
- (A) 실측 추력-베인각-복원모멘트 데이터를 **직접 회귀**해서 "뭉쳐진 CL"을 바로 구한다 → 지금 코드
  구조(`CLalpha`를 뭉쳐진 CL로 취급) 그대로 써도 됨. **다만 `params.yaml`의 변수명 `CLalpha`를
  `CL_lumped`같은 걸로 바꿔서 혼동 방지 권장.**
- (B) 논문처럼 raw `CLα`(에어포일 자체 특성) + `A_fin`(베인 면적, 실측 가능: 25×45mm) + `A_duct`
  (EDF 배기 단면적, `cad/hopper_params.scad`의 `edf_clamp_id` 근처 값으로 근사 가능)를 따로 구해서
  식 3.16대로 곱한다 → 코드에 `A_fin/(2*A_duct)` 항을 추가해야 함.

## 3. 회전 동역학 (§3.3)

**바디 프레임 토크** (Fig 3.7, l=COM~베인 조인트 거리, r=z축~베인 중심 거리):

```
τx = (F1+F3)·l
τy = -(F2+F4)·l
τz = (F1-F2-F3+F4)·r          (식 3.19)
```

**오일러 방정식**(대각 관성 가정 대입, 식 3.22):

```
ω̇x = (1/Jxx)[(F1+F3)l + (Jyy-Jzz)ωy·ωz]
ω̇y = (1/Jyy)[-(F2+F4)l + (Jzz-Jxx)ωx·ωz]
ω̇z = (1/Jzz)[(F1-F2-F3+F4)r + (Jxx-Jyy)ωx·ωy]
```

**월드(오일러각) 변환** — ZYX Tait-Bryan (식 3.24):

```
φ̇ = ωx + ωz·cosφ·tanθ + ωy·sinφ·tanθ
θ̇ = ωy·cosφ - ωz·sinφ
ψ̇ = (ωz·cosφ + ωy·sinφ) / cosθ
```

→ **코드 대응 확인 완료**: `hopper_aviary.py`의 `tau_x/tau_y/tau_z`, `wx_dot/wy_dot/wz_dot`,
`phi_dot/theta_dot/psi_dot` 모두 위 식과 **정확히 일치**(부호 포함). 여기는 논문 그대로 잘 옮겨졌다.

무게중심-추력축 오프셋(`cg_offset_x/y`, `params.yaml`의 `domain_rand.cg_offset_mm`)은 **논문엔 없는
우리 자체 추가**— 조립 오차로 인한 잔류 토크를 근사하려고 넣은 것(τx += cg_offset_y·Ft 등). 타당한
확장이지만 "논문에 없는 부분"이라는 것만 기록.

## 4. 병진 동역학 (§3.4) — Stage 1엔 미사용, Stage 2용 참고

바디프레임(식 3.29) → 월드프레임(식 3.31) 가속도/속도 식. **위치(x,y,z)까지 제어하는 건 Stage 2**
(위치 구속 M1을 풀고 자유비행 갈 때) — Stage 1(`HopperAttitudeEnv`)은 자세(φ,θ,ψ,ωx,ωy,ωz) 6개
상태만 쓰고 위치·속도는 없음. Stage 2 만들 때 이 절을 그대로 가져다 쓰면 됨.

## 5. 선형화 · 상태공간 (§3.5) — 논문은 LQR용, 우리는 지금 안 씀

논문은 호버점(φ=θ=0, Ft=mg)에서 야코비안 선형화해 12차원 상태공간 모델(식 3.41–3.43)을 만들고
Ch.4에서 LQR 게인을 설계한다. **우리 Stage 1은 이 선형화를 안 거치고 비선형 방정식을 numpy로 직접
적분**(오일러 적분, dt=0.01s) — RL(PPO)은 선형 모델이 필요 없어서다. 이 절은:
- 나중에 **LQR을 PID 대신/추가로 baseline에 넣고 싶으면** 그때 필요 (`AGENTS.md` PID vs RL 프로토콜
  참고 — 지금은 PID 또는 LQR 둘 다 "baseline" 후보로 열어둠).
- 제어 입력 벡터 정의 `u=[α1,α2,α3,α4,ωt]`(식 3.37)는 **우리 action space(5차원, `hopper_aviary.py`)와
  구조가 동일** — 단 우리는 ωt 대신 정규화된 throttle을 씀.

## 6. 코드 ↔ 논문 대응표

| 논문 기호 | 코드 변수 (`hopper_aviary.py`) | 상태 |
|---|---|---|
| `φ,θ,ψ,ωx,ωy,ωz` | `phi,theta,psi,wx,wy,wz` (state) | 일치 |
| `α1..α4` | `a1..a4` → `alpha` (action×alpha_max) | 일치 |
| `ωt` | `omega_t_equiv = throttle*3000` | **근사 — 실제 RPM 아님, 실험 A 후 교체 필요** |
| `Kf` | `params.yaml: Kf` | PLACEHOLDER |
| `Jxx,Jyy,Jzz` | `params.yaml: Jxx,Jyy,Jzz` | PLACEHOLDER |
| `l, r` | `params.yaml: vane_arm_l, vane_arm_r` | **실측 아님 표시돼 있었으나 실제로는 `cad/hopper_params.scad`(베인링 반경 96mm) 기반값 — PLACEHOLDER 아님** |
| `CLα, CD0` (raw) | `params.yaml: CLalpha, CD0` | PLACEHOLDER, **§2의 lumped-CL 이슈 있음 — 교체 시 위 (A)/(B) 중 택1 명시할 것** |
| `Cn = CLα·A_fin/(2A_duct)` (lumped) | 코드에 없음(위와 동일 취급 중) | 위 참고 |
| `τx,τy,τz` | `tau_x,tau_y,tau_z` | 일치 |
| Tait-Bryan 변환 W_η | `phi_dot,theta_dot,psi_dot` 계산부 | 일치(특이점 클리핑은 코드가 더 방어적) |
| 무게중심 오프셋 | `cg_offset_x/y` | **논문에 없음, 우리 자체 추가**(도메인 랜덤화용) |
| 병진 동역학 (§3.4) | 미구현 | Stage 2용 |
| 선형화/상태공간 (§3.5) | 미구현 | LQR 채택 시 필요 |

## 7. 다음에 할 일

1. 실험 A(EDF 추력곡선) → `Kf` 실측, `omega_t_equiv`를 실제 DShot RPM으로 교체.
2. 베인 힌지모멘트·제어효과 실측(TC-2, 마스터 설계도 §11) → §2의 (A) 직접회귀 또는 (B) 기하기반 중 결정.
3. 조립 후 CAD 질량속성으로 §1의 "관성 대각 가정"이 우리 기체에서도 맞는지 확인.
4. Stage 2 착수 시 §4(병진 동역학) 이식.

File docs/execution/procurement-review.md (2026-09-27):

# 구매 리스트 검토 (시트 대조)

부장이 만든 구글 시트의 A~G 항목을, `BOM-revC-teensy.md` 스펙과 대조한 것.
**시트에 "적합여부"·"조치" 두 열을 추가해서 아래 내용을 붙여넣으면 됨.**

## 범례

| 표시 | 뜻 |
|---|---|
| ✅ | 스펙 맞음, 그대로 주문 |
| ⚠️ | 링크 확인 필요 (아래 조건 충족하면 OK) |
| ❌ | 교체 필요 |
| ⏸️ | 지금 불필요, 나중(STAGE 3+) |
| ➕ | 시트에 없음, 추가 주문 필요 |

> 링크를 직접 못 열어봐서(타오바오 로그인 벽), ⚠️는 리스팅에서 조건 확인 후 판단.

---

## A · 추진 · 전원

| # | 시트에 고른 것 | 우리 스펙 | 적합? | 조치 / 비고 |
|---|---|---|---|---|
| A1 | 64mm EDF 3S/4S 3500KV ¥159 | 64mm, 4S, 추력 1.3kg↑, 전류 ESC 이내 | ⚠️ | **4S 전류 확인이 핵심.** ≤52A → OK(단 A4는 1300mAh). 53~65A → A2를 80A, A4를 1300mAh. 65A↑/불명 → 4S 전용 2840~3000KV 제품으로 교체. + 모터 포함·하우징 외경·볼트PCD 확인 |
| A2 | ESC 일반 DShot | 4S, DShot, 전류 여유 | ⚠️ | A1 전류 확정 후: **60A(EDF ≤52A) 또는 80A(그 이상).** BLHeli_32/AM32, 4S(3–4S 또는 2–6S) 지원 확인. 신호선 + BEC선 있는지 |
| A3 | Low ESR 전해 캐패시터 | 470µF, 25V↑ | ⚠️ | **정격전압 35V 권장**(4S 만충 16.8V, 스파이크 여유). 470~1000µF |
| A4 | LiPo 4S 850mAh ×2 | 4S, XT60, 고C | ❌→⚠️ | **1300mAh 4S로 권장.** 850은 너무 작음(런타임 45초, C레이트 빠듯). 1300mAh **75C↑**, XT60. 2~3개 |
| A5 | UBEC | 5~6V 출력, 3A↑ | ✅ | 출력 5V 또는 6V, 3A 이상이면 OK |

## B · 비행 컴퓨터 · 센서 · 통신

| # | 시트에 고른 것 | 우리 스펙 | 적합? | 조치 / 비고 |
|---|---|---|---|---|
| B1 | Teensy 4.0 (핀헤더 포함) | PJRC 정품 Teensy 4.0 | ⚠️ | **정품 확인** (PJRC 로고, 정상 부트로더 칩). 클론 주의. 핀헤더 납땜 필요 |
| B2 | BNO085/BNO080 모듈 ×2 | BNO08x 칩, I2C | ✅ | 칩이 BNO085 또는 BNO080이면 OK. ×2(예비) 좋음 |
| B3 | 텔레메트리(ESP32?) | ESP32-WROOM devkit | ⏸️ | **지금 생략 가능** (Teensy SD카드 로깅으로 대체). STAGE 2에 추가. 살 거면 최저가 클론 OK |
| B4 | SBUS 수신기 | RC 조종+킬 채널 | ❌ | **조종기가 없으므로 수신기 단품은 안 됨 → 송수신기 세트로 교체.** 아래 §교체 참고. + SolidGeek 코드는 **PWM 입력**을 읽으므로 PWM 출력 되는 수신기가 오히려 편함 |
| B5 | 부저·아밍 LED | 상태 알림(선택) | ✅ | 필수는 아님. 5V 액티브 부저 + LED면 충분. 있으면 편함 |
| B6 | 물리 킬스위치 | 배터리 경로, ≥80A | ⚠️ | **정격 전류 확인 (≥80A, 배터리 메인 경로용).** 조명용 저전류 스위치면 안 됨. 대안: XT60 안티스파크 + 물리 분리. (RC 조종기 킬 채널이 1차, 이건 2차 백업) |
| B7 | ToF 라이다 (VL53L1X) | 고도, STAGE3+ | ⏸️ | 지금 불필요. STAGE 3 홉 단계에 |
| B8 | 광류센서 (PMW3901) | 수평위치, STAGE3+ | ⏸️ | 지금 불필요. STAGE 3에 |
| B9 | **Teensy ↔ 컴퓨터 USB 데이터 케이블** | Micro-B ↔ USB-A/USB-C, 데이터 통신 지원, 2m 권장 | ➕ | **충전 전용 케이블 불가.** 펌웨어 업로드·USB 시리얼 로그·STAGE 1 급전에 필수 |

## C · 자세제어(베인) · 액추에이터

| # | 시트에 고른 것 | 우리 스펙 | 적합? | 조치 / 비고 |
|---|---|---|---|---|
| C1 | 서보 ×6 | MG90S **금속기어** 9g | ⚠️ | **MG90S(금속기어) 확인** — SG90(플라스틱)이면 안 됨. 6개 = 4 + 예비 2 ✅ |
| C2 | 베인 스파 Ø3mm CF, 0.5m 재단 | Ø3mm CF **로드(속 찬 봉)** | ✅ | 스파는 속 찬 봉이 맞음(베인 내부 보강). 0.5m 재단 요청 OK |
| C3 | 베인 피벗 Ø3mm 황동봉 + 부싱 | Ø3mm 황동 + 부싱 | ✅ | |
| C4 | 푸시로드 피아노선 | Ø1.5~2mm 피아노선 + Z벤드 | ✅ | Z벤드 플라이어 or 클레비스 있으면 좋음 |
| C5 | 서보혼 ×4 | MG90S 알루미늄 싱글암 | ⚠️ | **MG90S 스플라인 규격(25T)** 맞는지 확인 |

## D · 구조

| # | 시트에 고른 것 | 우리 스펙 | 적합? | 조치 / 비고 |
|---|---|---|---|---|
| D1 | 기둥 로드 Ø6mm 1m | Ø6mm CF **튜브(관, 속 빔)** | ⚠️ | **碳纤维管(튜브) 확인** — 碳纤维棒(속 찬 봉)이면 무겁고 과함 |
| D2 | 착륙다리 로드 Ø6mm 1m | 위와 동일 | ⚠️ | 튜브 확인. D1과 같은 링크니 **2m 한 번에 주문** |
| D3 | 필라멘트 | **PETG** 1kg | ⚠️ | **PETG 확인 (PLA 아님).** 프린터가 230~250°C 노즐 가능한지도 확인 |
| D4 | 상단 베일 Ø3mm 스틸봉 | Ø3mm 스틸봉 | ✅ | 굽힘 가공 필요 |
| D5 | 발 범퍼 폼 (EVA/EPP) | EVA/EPP | ✅ | |
| D6 | 그릴 메시 | 굵은 격자(≥8mm) | ✅ | 면적손실 <10%, 손가락 방호용 |

## E · 하드웨어 · 소모품

| # | 시트에 고른 것 | 우리 스펙 | 적합? | 조치 / 비고 |
|---|---|---|---|---|
| E1 | 볼트류 | M3/M4 + **열융착 너트(热熔铜螺母)** | ⚠️ | **M3 열융착 너트 포함 여부 확인** — 프린트 부품 나사산에 필수. 없으면 별도 추가(¥15) |
| E2 | 언더슬렁 소켓 M6 | M6 아이볼트/스터드 + 너트 | ✅ | |
| E3 | 접착·소모품 (에폭시+CA) | 5분/30분 에폭시, CA | ✅ | |
| E4 | 커넥터 (XT60/서보/불릿) | XT60, JR서보, 3.5mm 불릿 | ⚠️ | **열수축 튜브 포함인지 확인**, 없으면 추가 |
| E5 | 점퍼선·소형 브레드보드 | 배선용 | ✅ | 소형 만능기판(перф보드)도 같이 있으면 좋음(최종 배선용) |

## F · 구속 스탠드 (시트에 링크 없음 — ➕ 추가)

| # | 물품 | 사양 | 토요일 필요? | 조치 |
|---|---|---|---|---|
| F1 | 삼각대/모노포드 | 견고, 볼헤드 or 팬틸트 | ⏸️ Week2 | 학교에 있으면 생략 |
| F2 | 십자축 만능조인트 + 스러스트 베어링 | "十字轴万向节". **"相机云台" 아님!** | ⏸️ Week2 | ➕ 추가 |
| F3 | Ø8 스틸 연마봉 | 2 × 1m | ⏸️ Week2 | ➕ 추가 |
| F4 | Ø8 PTFE 부싱 | 4개 | ⏸️ Week2 | ➕ 추가 |
| F5 | 번지코드 + 카라비너 | | ⏸️ Week3+ | ➕ 추가 |
| F6 | **방호판 (폴리카보네이트) or 굵은 그물** | EDF 시험 방호벽 | 🔴 **토요일 필수** | ➕ **지금 주문** |

## G · 안전 (시트에 링크 없음 — ➕ 전부 추가, 토요일 전 도착)

| # | 물품 | 사양 | 조치 |
|---|---|---|---|
| G1 | LiPo 세이프백 | 중형 ×2 | ➕ 지금 |
| G2 | **밸런스 충전기 (AC 내장형)** | 4S, ≤1C, 예: ToolkitRC M6 / ISDT Q6 | ➕ **지금 (없으면 배터리 충전 불가 = 토요일 전원실험 불가)** |
| G3 | 소화기 | 일반/ABC | ➕ **학교에 있는지 먼저 확인**, 없으면 주문 |
| G4 | 보안경 | 인원수 + 여유 3개 | ➕ 지금 |
| G5 | 방화 장갑, 모래 버킷 | | ➕ 지금 |

---

## ❌ 교체: B4 → 송수신기 세트 (조종기 없음)

**추천: FlySky FS-i6X 송신기 + FS-iA6B 수신기** (~¥180~230)

| 항목 | 내용 |
|---|---|
| 왜 이거 | 저렴한데 이 용도엔 충분(실내 구속 호퍼는 장거리·저지연 불필요). 튜토리얼 방대, 안정적 |
| 채널 | 10채널(iA6B). **PWM 출력 6채널** — SolidGeek 코드가 PWM 입력을 읽으므로 **프로토콜 라이브러리 없이 바로 연결**. iBUS(1선 10채널)도 지원 — 라이브러리(`IBusBM`) 쉬움 |
| 킬 스위치 | 3단 스위치 채널 → 수신기 PWM → Teensy가 모터 컷. 안전 요건 충족 |
| 배선 | 수신기 CH1~4 = 스로틀·롤·피치·요, CH5 = 킬, CH6 = 예비 |
| 대안(더 좋음, 조금 비쌈) | **RadioMaster Pocket + ELRS 수신기** (~¥280~320). EdgeTX(오픈소스), ExpressLRS(CRSF 출력, Teensy에서 읽기 쉬움). 미래 확장성 좋으나 초보 세팅 난이도 ↑ |

→ **FS-i6X 세트로 가는 걸 권장.** 시트 B4를 "FlySky FS-i6X + FS-iA6B 세트"로 교체.

---

## ➕ 추가 필요 물품 전체 (시트에 새 행으로)

### 장비 (1회성 — 동아리가 계속 씀. 학교/랩에 있으면 생략)

| 물품 | 왜 | 대략가 |
|---|---|---|
| 디지털 캘리퍼스 | 부품 실측 → CAD. **토요일 필수** | ¥20~40 |
| 멀티미터 | 전자 브링업(전압·도통) | ¥30~60 |
| 밸런스 충전기 AC (= G2) | 4S LiPo 충전 | ¥200~350 |
| 인두기·솔더·플럭스, 니퍼, 와이어 스트리퍼 | 납땜·배선 | 있음(확인만) |
| Z벤드 플라이어 (선택) | 푸시로드 가공 | ¥30 |

### 소모품 (➕ 시트에 추가)

| 물품 | 왜 | 대략가 |
|---|---|---|
| 충전 케이블 (XT60 ↔ 충전기) | 배터리 충전 | ¥10 |
| micro SD 카드 8~32GB | Teensy 로깅 | ¥15 |
| **B9 USB 데이터 케이블** (Teensy=Micro-B ↔ 컴퓨터 USB-A/USB-C) | 펌웨어 업로드·USB 시리얼 로깅·STAGE 1 급전. **충전 전용 불가** | ¥15 |
| 실리콘 전선 14~16AWG(전원) + 24~26AWG(신호) | 전원·신호 배선 | ¥25 |
| 열수축 튜브 세트 | 절연 | ¥10 |
| M3 열융착 너트 (E1에 없으면) | 프린트 부품 나사산 | ¥15 |

---

## 주문 순서 (최종)

1. **A1 EDF 4S 전류 확인** → A2 ESC(60/80A)·A4 배터리(1300mAh) 확정
2. **B4를 FS-i6X 세트로 교체**
3. **B9 USB 데이터 케이블** + F6(방호) + G그룹 + 장비(캘리퍼스·멀티미터·충전기) 추가
4. ⚠️ 표시 항목 링크 확인 (튜브 여부, PETG 여부, MG90S 여부, 열융착 너트 여부)
5. ⏸️(B3·B7·B8·F1~F5) 빼고 나머지 전량 주문

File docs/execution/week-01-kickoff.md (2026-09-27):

# Week 1–2 실행 계획 (마스터)

첫 세션: **9/18(금) 1h + 9/19(토) 2h.** 지금(9/7)부터 ~11일 리드타임 → 준비·주문은 이 기간에 끝내고,
세션 3시간은 바로 실습·실측에 쓴다.

## 이 폴더 구성

| 파일 | 용도 |
|---|---|
| **이 문서** | 마스터 — 타임라인 · 부장 준비 · 부품 전체 리스트 · 세션 진행 |
| [`procurement-review.md`](procurement-review.md) | 부장 구글시트 행별 검토 (✅/⚠️/❌/➕) |
| [`bench-wiring.svg`](bench-wiring.svg) | 벤치 배선도 (Week 1 브링업 → Week 2 확장) |
| [`../design/BOM-revC-teensy.md`](../design/BOM-revC-teensy.md) | 전체 BOM 원본 |
| [`../design/00-hopper-master-design.md`](../design/00-hopper-master-design.md) | 마스터 설계도 rev C |
| [`../design/general-arrangement.svg`](../design/general-arrangement.svg) | 기체 개략 배치도 |
| [`../design/references/Jacobsen2021_*.pdf`](../design/references/) | SolidGeek 논문 (제작·제어 이론) |

---

## 1. 타임라인

| 시기 | 할 일 | 담당 |
|---|---|---|
| **~9/10** | 예산·결제수단 확정 → **부품 전량 주문** (§3) | 부장 |
| ~9/12 | 회원 명단, 팀 3개 사전 배정 / 소프트·CAD 코어 세팅 시작 | 부장 |
| **~9/15** | **안전 계획서 → 지도교사 서명** (토요일 EDF 시험의 전제) | 부장 + 실험·운영 코어 |
| ~9/14–16 | 부품 도착 (중국 내 2–4일) | — |
| 9/16–17 | 핵심 4개 실측 → CAD 반영 / 상판·베인링·어댑터 프린트 시작 | 부장 + 기구 코어 |
| 9/17 | 토요일 스테이션 3개 셋업 (§2-F) | 전체 코어 |
| **9/18 금 1h** | 전체 브리핑 + 팀 확정 + 팀별 착수 (§4) | 전체 |
| **9/19 토 2h** | 실험 A(추력) · B(IMU) · C(DShot) + CAD·프린트 병행 (§5) | 전체 |
| 9/22~ (Week 2) | 프레임 조립, 구속 스탠드 제작, 시뮬 착수 (§6) | 전체 |

---

## 2. 부장이 1주차 전까지 준비할 모든 것

### 2-A · 행정 · 자금
- [ ] 예산 승인 (₩300~450k 규모 — §3 참고)
- [ ] 결제 수단: 타오바오 계정 + 알리페이/위챗페이 연결, 영수증 정산 방식
- [ ] 회원 명단 (이름·학년·연락처·위챗), 팀 3개 사전 배정 (기구·전자 / 소프트웨어 / 실험·운영)
- [ ] 랩/실습실 사용 요일·시간 확정, 위챗 단톡 개설, 공유 드라이브/GitHub 접근 배포

### 2-B · 주문
- [ ] `procurement-review.md`의 ⚠️ 항목 링크 확인 (4S 전류, 튜브 여부, PETG, MG90S, 열융착 너트)
- [ ] B4를 **FlySky FS-i6X + FS-iA6B 세트**로 교체
- [ ] §3의 🔴 + 🟠 + ➕ 전량 주문 (⏸️만 제외)

### 2-C · 안전 승인 ← 하드 데드라인 9/15
- [ ] 안전 계획서 v1 작성 — 포함: TC-0(구속+스로틀만) 절차 / LiPo 수칙(방화용기·1C 충전·손상시 폐기) /
      회전체 방호(그릴·방호판·보안경·인원 거리) / 물리 킬스위치 + RC 킬 채널 / 비상 대응(소화기 위치)
- [ ] 지도교사 미팅 → **서명 받기** (이거 없으면 토요일 EDF에 전원 못 넣음)
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

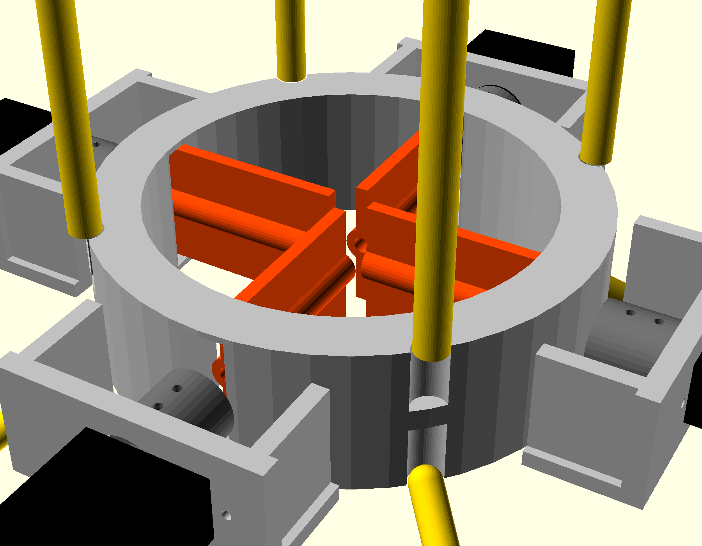
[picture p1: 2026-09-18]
cad/renders/vane_ring_closeup.png

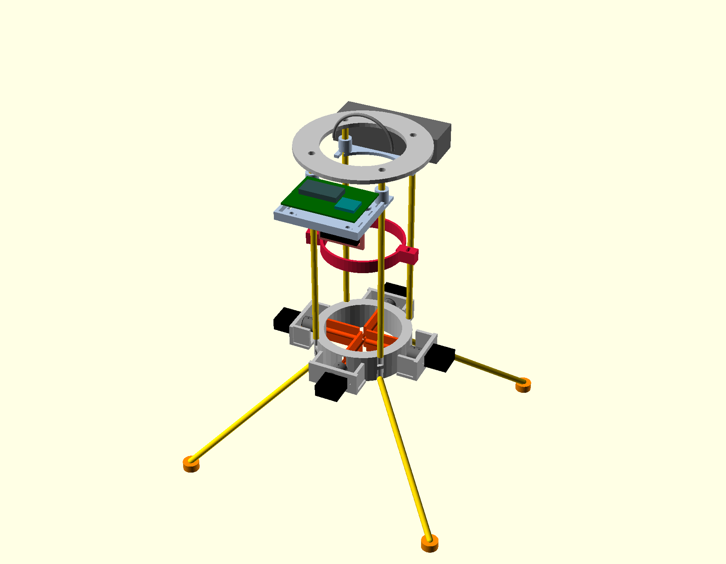
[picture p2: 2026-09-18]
cad/renders/preview_colored.png

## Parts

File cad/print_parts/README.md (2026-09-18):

# cad/print_parts/ — 외주 프린트용 STL

**2026-09-18: 실제로 export 완료.** 예전엔 이 폴더가 계속 비어 있었다(OpenSCAD 로컬 미설치로 알고
있었는데, 실제로는 `Program Files\OpenSCAD\`의 설치가 깨져 있었을 뿐이고 — 진짜 실행파일은
`C:\Users\mimin\Desktop\openscad.exe`(2021.01)에 있었다). 그 실행파일로 9개 파츠를 전부 렌더·export했다.

| 파일 | 내용 |
|---|---|
| `top_plate.stl` | 상판 |
| `vane_ring.stl` | 베인링(서보 보스·스파 보어·하드스톱 슬롯 포함) |
| `vanes_x4.stl` | 베인 4개(한 시트) |
| `edf_clamp.stl` | EDF 분할 클램프(2조각) |
| `battery_shelf.stl` | 배터리 선반(+Y) |
| `avionics_shelf.stl` | 아비오닉스 선반(−Y, 만능기판 인서트 포함) |
| `esc_bracket.stl` | ESC 브래킷 |
| `vane_couplers_x4.stl` | 서보혼↔스파 커플러 4개 |
| `foot_pads_x4.stl` | 발 범퍼 4개 |

## 재현 방법 (수치가 바뀌었을 때 다시 export하려면)

`hopper_params.scad`는 `render_mode`(preview/print) 하나로만 나뉘어 있어서, "print"로 렌더해도 9개
파츠가 한 덩어리로 합쳐져 나온다 — **개별 STL을 얻으려면 파일 맨 아래 조립 섹션을 부품 하나 호출로
바꾼 임시 사본을 만들어 export해야 한다** (진짜 소스 파일은 건드리지 않는다 — 다른 세션이 계속
`hopper_params.scad`를 고치고 있어서 충돌 위험이 있다).

1. `hopper_params.scad`의 1~516행(변수·모듈 정의부, `// ---------- 조립 ----------` 주석 앞까지)을
   임시 파일로 복사.
2. 그 뒤에 원하는 파츠 호출 한 줄만 추가(아래 표 — 이건 소스 파일의 "print" 분기에 있는 호출을 그대로
   옮긴 것):

   | 파츠 | 추가할 줄 |
   |---|---|
   | top_plate | `translate([0,0,top_plate_bot_z]) top_plate();` |
   | vane_ring | `vane_ring();` |
   | vanes_x4 | `vanes();` |
   | edf_clamp | `edf_clamp();` |
   | battery_shelf | `rotate([0,0,90]) equip_shelf_battery();` |
   | avionics_shelf | `rotate([0,0,270]) equip_shelf_avionics();` |
   | esc_bracket | `rotate([0,0,270]) esc_bracket();` |
   | vane_couplers_x4 | `for (i=[0:n_vanes-1]) rotate([0,0,i*360/n_vanes + az_vane]) translate([servo_mount_r + 1.5, 0, vane_pivot_z]) vane_coupler();` |
   | foot_pads_x4 | `foot_pads();` |

3. `openscad.exe --render -o <파츠이름>.stl <임시파일>.scad`
4. 임시 파일 삭제(커밋 대상 아님).

GUI로 하고 싶으면 원래 방식(모듈 하나만 남기고 나머지 주석 처리 → F6 → Export as STL)도 그대로 유효 —
위 방법은 그걸 커맨드라인으로 자동화한 것뿐이다.

## 다음 단계

- 슬라이서(Cura/PrusaSlicer)에서 치수·인필 확인 — 재료는 PETG(모터 폐열 대응, PLA 금지), 벽 4라인,
  인필 40%(`docs/design/00-hopper-master-design.md` §10-4).
- 외주 발주 전 §5.1(만능기판 실제 홀수)·§2.4(BNO085 SPI 지원 패드)·§7.4(MG90S 이어 홀 간격) 등
  `docs/design/01-avionics-integration-final.md`의 "확인 포인트"를 실물로 재확인.
- 실제로 발주 넣을 때 그 시점 STL을 `cad/print-orders/<날짜>/`로 복사해서 커밋(`.gitignore` 예외).

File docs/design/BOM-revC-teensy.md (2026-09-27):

# BOM — 착륙 호퍼 rev C (Teensy 4.0 / SolidGeek 베이스 + 단일 EDF)

`research-open-source-references.md` §6 권장안 채택판. rev B(F405 WING + ArduPilot SingleCopter)에서
**비행 컨트롤러·센서·통신 계통을 SolidGeek/SingleRotorUAV 방식으로 교체**, 추진·구조·안전 계통은 rev B 유지.

> 마스터 설계도는 `00-hopper-master-design.md` rev C로 이미 갱신됨. 이 문서는 그 구매 리스트.
>
> **2026-09 갱신 — 예산형 사양 반영.** 구조·아키텍처(Teensy+BNO08x+단일EDF+베인, SolidGeek 포크)는
> **그대로 두고**, 부품 등급·소싱만 낮춰 rev B와 비슷한 금액대로 맞췄다. 아래 표의 "예산형"이 기본 권장값 —
> 코드 호환성·논문 재현성엔 영향 없음(같은 칩, 같은 프로토콜, 브랜드/용량만 다름).

## 뭐가 바뀌었나 (rev B → rev C)

| 계통 | rev B | **rev C** | 이유 |
|---|---|---|---|
| 비행 컴퓨터 | SpeedyBee F405 WING (ArduPilot) | **Teensy 4.0** (SolidGeek 코드 포크) | CLAUDE.md의 "Teensy 대안"을 검증된 오픈소스로 실현. RL 이식이 쉬운 구조 |
| 자세 센서 | F405 내장 ICM-42688P + SPL-06 바로미터 | **BNO085 IMU 브레이크아웃** (센서퓨전 내장, 쿼터니언 직접 출력) | SolidGeek 코드가 이 칩 기준. 바로미터는 STAGE 1(구속)엔 불필요 → 제외, 홉 단계에서 ToF로 대체 |
| ESC | 60A 4S, BEC만 | **60A 4S, 양방향 DShot(RPM 텔레메트리) 지원 필수** | Bresciani의 자이로스코픽 정차 보정 로직에 로터 RPM이 필요 |
| 텔레메트리 | FC 내장 로깅 | **ESP32 개발보드 추가** (SolidGeek 방식, WiFi 지상국) | 시험 데이터 로깅 = PID/RL 비교의 핵심 산출물 |
| 수신기 | Spektrum 재사용 가정 | 그대로, 단 **Teensy에서 읽는 방식 2가지 중 택1** (아래 B4) | |
| 추진(EDF)·서보·구조·다리·구속·안전 | — | **rev B 그대로 유지** | 이 부분은 아키텍처 무관하게 검증됨 |

---

## A. 추진 · 전원 (rev B와 동일 — 재확인만)

| # | 부품 | 사양 | 수량 | 예상가(₩) | 비고 |
|---|---|---|---|---|---|
| A1 | 64mm EDF 파워시스템 | 4S, 11~12블레이드, 리버스 없음. 추력 1.3~1.46 kgf | 1 | 35–55k | Freewing 64 V2 3100KV 4S / FMS 64 4S. **구매 전 실제 리스팅의 추력·전류·무게로 §5 질량예산 재확인** |
| A2 | ESC — **예산형: 일반 DShot** (양방향 텔레메트리 없어도 됨) | BLHeli_32/AM32, 60A, 4S, DShot600 | 1 | **15–25k** | 자이로 정차 보정(§6.7)은 TC-2.5 결과 보고 필요할 때만 추가 — SolidGeek 원 논문도 이 보정 없이 비행 성공(8.1.1절). **지금은 저렴한 일반 DShot ESC로 시작**, 나중에 문제 확인되면 양방향 DShot(RPM 텔레메트리) 지원 제품(25–40k)으로 교체 |
| A3 | 저ESR 캐패시터 | 470µF/25V | 1 | 1k | |
| A4 | LiPo — **예산형: 850mAh** | 4S 850mAh 50C+ (XT60) | 2 | 10–15k/ea | STAGE 1(구속 시험)은 런타임이 중요하지 않음 — 용량 줄여도 무방. 무게도 -50g/개, TWR 오히려 소폭 개선. 1300mAh 3개(rev C 초안, 45–66k)보다 **20–35k 절감** |
| A5 | UBEC | 5V/3A (서보·Teensy 백업 전원) | 1 | 5k | ESC BEC 있으면 이중화용 |

## B. 비행 컴퓨터 · 센서 · 통신 (**rev C 핵심 변경**)

| # | 부품 | 사양 | 수량 | 예상가(₩) | 비고 |
|---|---|---|---|---|---|
| B1 | **Teensy 4.0** (핀 헤더 포함) | ARM Cortex-M7 600MHz | 1 | **28–38k** | PJRC 정품을 **AliExpress 직구**로 사는 게 보통 제일 쌈(타오바오 리셀러는 수입마진 붙어 더 비쌀 수 있음). 클론 없음(정품만 존재) — 가격 편차는 배송비 차이 |
| B2 | IMU 브레이크아웃 — **예산형: 중국 범용 BNO085/BNO080 모듈** | 9-DOF 센서퓨전 내장, I2C, 쿼터니언 직접 출력 (Adafruit STEMMA 커넥터 없는 맨보드) | 1 (+예비 1) | **8–15k** | **같은 칩**이라 SolidGeek 코드 그대로 호환. Adafruit 정품(25–35k)은 STEMMA QT 커넥터·품질보증 프리미엄일 뿐 — 기능은 동일. 타오바오에서 "BNO085 모듈" 검색 |
| B3 | ESP32 개발보드 — **예산형: 생략 또는 최저가 클론** | WiFi, ESP32-WROOM 계열 | 0~1 | **0–5k** | STAGE 1은 Teensy 자체 SD카드/시리얼 로깅으로 대체 가능 — **지금 안 사도 됨**. 실시간 지상국이 필요해지면(STAGE 2~) 그때 최저가 클론(~3–5k)으로 추가 |
| B4 | RC 수신기 | 아래 2안 중 택1 | 1 | 0~15k | **킬 채널 필수** |
| B4-a | ↳ (A) 기존 Spektrum 위성 재사용 | 지난 학기 세트 재고 확인 | — | 0 | Teensy에 무료 Arduino 라이브러리(`DSMRX` 계열)로 DSM2/DSMX 시리얼 디코드 — 코드 몇 줄, 새 하드웨어 불필요 |
| B4-b | ↳ (B) 신규 구매 시 SBUS 출력 수신기 | 저가 6ch+ SBUS RX | 1 | 10–15k | SolidGeek 원 설계와 동일 사상(단순 PWM/시리얼 입력). SBUS 디코드 라이브러리도 흔함 |
| B5 | 부저 · 아밍 LED | 수동 | 1세트 | 3k | |
| B6 | 물리 킬스위치 | 고전류 인라인 스위치(배터리 경로) | 1 | 6k | |
| B7 | *(STAGE 3+ 홉 단계 전용, 지금 안 사도 됨)* VL53L1X ToF 라이다 | 고도 측정(실내 저고도) | 1 | 8–12k | 바로미터 대신 — 구속 시험 단계엔 불필요, 자유 홉 갈 때 추가 |
| B8 | *(선택, STAGE 3+)* PMW3901 광류센서 | 수평 위치 유지 | 1 | 15–20k | 자유 홉 위치제어용 — STAGE 1은 불필요 |
| B9 | **Teensy ↔ 컴퓨터 USB 데이터 케이블** | Teensy 쪽 Micro-B, 컴퓨터 쪽 USB-A 또는 USB-C, **데이터 통신 지원**, 2m 권장 | 1 | 3–5k | 펌웨어 업로드·USB 시리얼 로깅·STAGE 1 급전에 필수. **충전 전용 케이블 불가** |

## C. 자세제어(베인) · 액추에이터 (rev B와 동일)

| # | 부품 | 사양 | 수량 | 예상가(₩) | 비고 |
|---|---|---|---|---|---|
| C1 | 서보 | MG90S 금속기어 9g | 4 + 예비 2 | 4k/ea | 힌지모멘트 계산상 여유 큼 (rev B §6.3 재검증 완료) |
| C2 | 베인 스파 | Ø3mm CF 로드 | 0.5m | 3k | |
| C3 | 베인 피벗 | Ø3mm 황동봉 + 부싱 | 소량 | 3k | |
| C4 | 푸시로드 | Ø1.6mm 피아노선 + Z벤드 | 소량 | 3k | |
| C5 | 서보혼 | MG90S 알루미늄 싱글암 | 4 | 5k | |

## D. 구조 (rev B와 동일 — CAD만 SolidGeek Onshape 포크로 교체 검토)

| # | 부품 | 사양 | 수량 | 예상가(₩) | 비고 |
|---|---|---|---|---|---|
| D1 | 기둥 로드 | Ø6mm CF 튜브 (또는 알루 스탠드오프) | 1m | 10k | |
| D2 | 착륙다리 로드 | Ø6mm CF 튜브 | 1m | 10k | |
| D3 | 프린트 필라멘트 | PETG 0.5kg | 1 | 15k | PLA 금지(모터 폐열) |
| D4 | 상단 베일 | Ø3mm 스틸봉 | 소량 | 2k | |
| D5 | EVA/EPP 폼 | 발 범퍼 | 소량 | 2k | |
| D6 | 그릴 메시 | 흡·배기 방호 | 소량 | 4k | |

## E. 하드웨어 · 소모품

| # | 부품 | 수량 | 예상가(₩) |
|---|---|---|---|
| E1 | 볼트류(M3/M4) + 인서트 너트 | 세트 | 8k |
| E2 | 언더슬렁 소켓(M6 스터드+너트) | 1 | 2k |
| E3 | 에폭시·순간접착·케이블타이·열수축 | — | 12k |
| E4 | 커넥터(XT60, 서보, 3.5mm 불릿) | 세트 | 6k |
| E5 | 점퍼선·소형 브레드보드(Teensy-BNO085-ESP32 배선용) | 세트 | 5k |

## F. 구속 스탠드 (rev B와 동일 — 지난번 정정 반영)

| # | 부품 | 사양 | 수량 | 예상가(₩) | 비고 |
|---|---|---|---|---|---|
| F1 | 카메라 삼각대/모노포드 | 견고한 것 | 1 | 20–40k | 보유 시 ₩0 |
| F2 | **저마찰 자유회전 조인트** | 십자축 만능조인트(十字轴万向节)+스러스트 베어링/스위블. **"相机云台"(사진용 볼헤드) 검색 금지 — 마찰로 잠김** | 1 | 8k | |
| F3 | 수직 가이드 로드 | Ø8 스틸 연마봉 | 2×1m | 12k | |
| F4 | PTFE 부싱 | Ø8 내경 | 4 | 6k | |
| F5 | 번지코드+카라비너+로프 | — | 세트 | 10k | |
| F6 | 폴리카보네이트 스크린/그물 | 회전체 방호 | — | 20k | |

## G. 안전

| # | 부품 | 수량 | 예상가(₩) |
|---|---|---|---|
| G1 | LiPo 세이프백(중형) | 2 | 12k |
| G2 | 밸런스 충전기(4S, ≤1C) | 1 | 30k |
| G3 | 소화기+모래 버킷 | 1 | 25k |
| G4 | 보안경 | 인원수 | 3k/ea |

---

## 개략 합계 — 예산형(권장) vs 원안

| 그룹 | **예산형(권장)** | 원안(rev C 초안) | rev B |
|---|---|---|---|
| A 추진·전원 | **76–116k** | 100–160k | 90–170k |
| B 비행컴퓨터·센서·통신 | **48–87k** (STAGE1, B7·B8 제외) | 63–135k | 58–115k |
| C 베인·서보 | 25–40k | 25–40k | 25–40k |
| D 구조·필라멘트 | 40–65k | 40–65k | 40–65k |
| E 하드웨어·배선 | 30–45k | 30–45k | 25–40k |
| F 구속 스탠드 | 40–100k | 40–100k | 40–100k |
| G 안전 | 55–80k | 55–80k | 55–80k |
| **총계(STAGE 1)** | **≈ 313k – 535k** | ≈ 353k – 625k | ≈ 263k – 425k |

**절감 포인트 요약** (구조·코드 호환성엔 영향 없음, 부품 등급/소싱만 변경):
- ESC: 양방향 DShot → 일반 DShot로 시작, 필요시만 나중에 업그레이드 (−10~15k)
- 배터리: 4S 1300mAh×3 → 4S 850mAh×2 (−20~35k, STAGE1엔 런타임 안 중요)
- IMU: Adafruit 정품 → 중국 동일칩 범용 브레이크아웃 (−10~20k)
- ESP32: 지금 생략, Teensy 자체 로깅으로 대체, STAGE2+에 추가 (−6~12k)

이렇게 하면 **rev B와 거의 같은 금액대**로 SolidGeek 논문/코드를 그대로 따라가는 rev C 구조를 살 수 있다.
STAGE 3(홉) 갈 때 B7(ToF, +8~12k)·B8(광류, +15~20k), 필요시 ESC 업그레이드(+10~15k) 추가.

---

## 구매 순서 권장 (전체를 한 번에 안 사도 됨 — 이 순서대로 나눠 사도 됨)

**1차: A1(EDF) · B1(Teensy 4.0) · B2(IMU) · B9(USB 데이터 케이블) · A2(ESC)** — EDF·Teensy·IMU·ESC의 실물 치수(EDF 하우징 지름·마운트 볼트
간격, 보드 크기)가 CAD의 나머지 부분(모터마운트 소켓 크기, 배선 레이아웃)을 결정하기 때문에 **먼저 사서
실측**해야 그다음 프린트 설계가 정확해진다. B9는 Teensy 실물 업로드와 로그 확인에 바로 필요하다.
나머지(C~G)를 안 사고 이 항목들만 먼저 사도 무방.

2. 핵심 4개 부품 도착 → 실측 → SolidGeek Onshape 포크 모델의 모터마운트 파라미터 교체.
3. **2차**: C(서보)·D(구조 소재) — 프린트/재단 일정에 맞춰 구매.
4. **3차**: F·G(구속·안전) — 아키텍처와 무관해서 언제 사도 되고, 병렬로 준비 가능.
5. B3(ESP32)·B7(ToF)·B8(광류)는 STAGE 1 통과 후 필요할 때.

## 아직 결정 안 된 것

- **CAD를 SolidGeek Onshape에서 포크할지, rev B의 자체 파라메트릭(`cad/*.scad`)을 계속 쓸지** — 포크 쪽이 시간 절약이 크다는 게 리서치 결론이지만 최종 확정은 안 함.
- **수신기 B4-a vs B4-b** — 재고 확인 후 결정.
- 이 BOM 확정 시 `00-hopper-master-design.md`도 rev C로 개정 필요(치수·배선도·펌웨어 섹션 갱신) — 원하면 다음에 진행.

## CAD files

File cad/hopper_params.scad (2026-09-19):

// ============================================================
// PRJ-01 TVC 착륙 호퍼 — 파라메트릭 스켈레톤 (rev C, 오픈 스탠드오프 프레임)
// 참조: docs/design/00-hopper-master-design.md §4 (좌표계·전체 치수)
//
// 이 파일은 SolidGeek Onshape 포크의 "대안"으로 마스터 설계도가 언급한
// cad/*.scad 경로를 실제로 구현한 것. §4 표의 심볼명을 그대로 변수명으로 썼다.
//
// ⚠️ 지금 값은 전부 "DESIGN(가정)" — 부품 도착 후 캘리퍼스 실측하면
//    아래 "MEASURED — 실측 후 이 값만 바꾸면 됨" 섹션만 고치면 전체 형상이 갱신됨.
// ============================================================

// ---------- MEASURED — 실측 후 이 값만 바꾸면 됨 ----------
// 2026-09-13 실측: 이 EDF는 마운트 볼트 플랜지가 없는 제품으로 확인됨
// (사진 확인 결과 하우징 중심부 4홀은 모터→허브 내부 고정용, 프레임 마운트용 아님)
// → PCD/볼트홀 방식 대신 분할 클램프(collar clamp) 방식으로 설계 변경
// 2026-09-18 재측정(2차): 줄자 둘레 22.6cm(앞) / 21.9~22cm(뒤) → 지름 환산 71.9mm / 69.9mm.
//   1차 측정(22.7cm/22cm → 72mm/70mm)과 오차 0.5mm 이내로 일치 — 값 그대로 유지, 재확인만 기록.
edf_housing_od   = 72;   // EDF 하우징 외경 (mm) — 줄자 둘레 22.6~22.7cm ÷ π 환산값 (앞쪽 넓은 부분, 클램프 기준). 2회 측정 일치
edf_body_od_min  = 70;   // 참고: 뒤쪽(모터쪽) 둘레 21.9~22cm ÷ π 환산값 — 단차 작아 설계상 무시, 클램프가 오차 흡수. 2회 측정 일치
edf_has_bolt_flange = false;  // 이 제품엔 볼트 플랜지 없음 → 클램프 마운트로 전환
edf_clamp_gap      = 3;      // 클램프 내경 여유 (실측이 정확하지 않을 수 있어 1.5→3mm로 확대, 슬롯홀과 함께 오차 흡수)
edf_clamp_h        = 12;     // 클램프 밴드 폭(높이, mm)
edf_body_len        = 92;    // EDF 몸통 세로 길이(mm) — 배기면(z=0) ~ 흡입구 립 끝. 실측 9~9.3cm 평균
edf_clamp_z_from_exit = 70;  // 배기면(z=0) 기준 클램프 높이 — 립 근처(72mm 지름 구간)를 잡도록 흡입구 쪽에 가깝게 배치

// ---------- DESIGN — §4 표 값 그대로 (구조 결정 후 바뀌면 여기 수정) ----------
col_len              = 200;  // 기둥 길이(상판~베인링)
top_plate_t          = 4;    // 상판 두께
vane_ring_h          = 28;   // 베인 링 높이
vane_gap_below_exit  = 22;   // EDF 배기면 → 베인 피벗축
foot_below_exit      = 140;  // EDF 배기면 → 발 바닥
H_total              = 350;  // 전체 높이(베일 팁~발), 참고용 — 검증에 사용
foot_circle          = 360;  // 발 원 지름
leg_len              = 210;  // 다리 길이(로드, 참고용 — 실제 배치는 아래서 계산)

vane_chord = 25;   // 베인 시위
vane_span  = 45;   // 베인 스팬
vane_thick = 2.5;  // 베인 두께
n_vanes    = 4;

col_od   = 6;   // D1 기둥 로드 Ø6mm CF 튜브
leg_od   = 6;   // D2 다리 로드 Ø6mm CF 튜브
n_cols   = 4;
n_legs   = 4;

bail_od  = 3;   // D4 상단 베일 Ø3mm 스틸봉

// ---------- 장비 선반(아비오닉스·배터리) · 서보 · 발 ----------
// rev C.1 (2026-09-17): 원점 중심 "트레이" 2개를 폐기하고 **기둥에 걸치는 장비 선반**으로 교체.
//   폐기 이유 3가지 — ①흡기 통로(상판 흡기홀 ~ EDF 립 사이) 한가운데를 막고 있었음
//   ②판 반길이(55.5) > 기둥 반경위치(33.9)라 기둥 4개를 관통 ③어디에도 고정되지 않는 떠 있는 판.
//   상세 근거·치수 출처: docs/design/01-avionics-integration-final.md §7
// ⚠️ 부품 공칭 치수는 실측 아님 — 실물 받으면 여기만 조정(규격품이라 거의 안 바뀜).
// 2026-09-19 실측 최종 확정(2차 — 9/18 1차값 대체, cad/measurements.md 원본 기록):
//   - Teensy 35×17mm — 공식 스펙(36×18mm)과 거의 일치. 1차 "세로 10mm"는 측정 오류였던 걸로 확인.
//   - 배터리 63.5×32.5×15mm(가로×세로×두께) — 1차값(74×34, 높이 미측정)을 전부 교체.
//     세 축 다 실측 완료, 더 이상 플레이스홀더 아님.
teensy_l = 35; teensy_w = 17;             // Teensy 4.0 실측(최종) — 미리보기 전용, 프린트 파츠엔 안 쓰임
esc_l    = 36; esc_w    = 24; esc_t = 8;  // ESC 보드 (브래킷 크기 산정용) — 아직 미측정, 공칭치수
batt_l = 63.5; batt_w = 32.5; batt_h = 15; // 배터리 실측(최종) — 3축 전부 측정 완료

shelf_top_z   = 150;   // 선반 윗면 z (배기면 기준). 상판 하면(178)까지 28mm, EDF 립(92)에서 58mm 위
shelf_t       = 3;     // 선반 판 두께
shelf_rib_h   = 5;     // 가장자리 리브 높이 (캔틸레버 처짐 방지)
shelf_r_inner = 42;    // 선반 안쪽 경계 반경 — 흡기 스트림튜브(Ø78=r39) + 여유 3mm. 이보다 안쪽엔 재료 없음
saddle_h      = 16;    // 기둥을 감싸는 새들 링 높이
saddle_wall   = 2.9;   // 새들 링 두께
tie_slot_w    = 3.2;   // 케이블타이 슬롯 폭 (2.5mm 타이 기준)
tie_slot_l    = 8;     // 케이블타이 슬롯 길이

// 만능기판(5x7cm) 장착 — 01-avionics-integration-final.md §5.1 의 확공 좌표와 1:1
perf_hole_dx  = 53.34; // C2↔C23 = 21홀 × 2.54
perf_hole_dy  = 38.10; // R2↔R17 = 15홀 × 2.54
insert_d      = 4.2;   // M3 열융착 인서트 하부 구멍 (제품에 따라 4.0~4.6 — 실물 확인)
insert_h      = 6;

// MG90S 서보 (베인 직결 구동) — 2026-09-19 실물 SG90(캘리퍼스 대용, MG90S와 케이스 규격 동일
// "드롭인 호환" 관계라 마운트 치수 대용 측정 유효) 캘리퍼스 실측. 전 항목 실측 완료(2026-09-19,
// 3차 — "몸통 폭 2.3"/"축은 0.3"을 다른 항목으로 잘못 재해석했던 걸 정정, cad/measurements.md 참고).
servo_body_l  = 22.8;  // 접선 방향 길이(몸통 긴변) — ⚠️ 아직 미측정, 조사자료 기반 플레이스홀더
servo_body_w  = 23;    // 수직 방향 폭(두께) — 실측 확정(2.3cm)
servo_body_h  = 28;    // 반경 방향 깊이(출력축 방향, 축 보스 제외 케이스만) — 실측 확정(2.8cm)
servo_ear_pitch = 33;         // 이어 홀 간격 — 실측 확정(3.3cm). 조사자료(28.0) 대비 5mm 큼
servo_ear_to_shaft = 3;       // 출력축 ↔ 가까운 쪽 이어 홀 거리 — 실측 확정(0.3cm). 조사자료(9.9)보다 훨씬 짧음
                              // → 이어 홀이 비대칭 배치가 돼서 servo_boss_solid()의 boss_y 계산을
                              //   아래에서 "양쪪 홀을 다 덮는 최소폭" 방식으로 고쳤음(2026-09-19)
servo_screw_d = 1.7;         // M2 셀프탭 하부 구멍
servo_boss_t  = 4;           // 서보 장착판 두께(반경 방향)
servo_standoff = 16;         // 링 바깥면 ↔ 장착판 사이 캐비티 깊이 (혼 + 스파 커플러가 들어감)

coupler_len        = 14;     // 스파 커플러 길이(반경 방향)
coupler_d          = 14;     // 커플러 바깥 지름
coupler_horn_t     = 2.2;    // ⚠️ 실측: 알루미늄 싱글암 혼 두께
coupler_horn_w     = 9.0;    // ⚠️ 실측: 혼 암 폭
coupler_horn_depth = 9;      // 혼이 커플러에 물리는 깊이

vane_spar_d       = 3.0;     // C2 Ø3 CF 스파
vane_spar_bore    = 3.2;     // 스파 관통 보어
vane_inner_r      = 4;       // 베인 안쪽 끝 반경 (모터 허브 후류 회피)
vane_stop_deg     = 15;      // ±기계 하드스톱 각도 (링 벽 슬롯이 스톱 역할)

foot_pad_d = 16; foot_pad_h = 8;             // D5 EVA/EPP 발 범퍼

$fn = 48; // 렌더 품질 (렌더 느리면 24로 낮추기)

// ---------- 좌표계 ----------
// z = 0 : EDF 배기면 (§4 기준면). 위로 +z, 아래로 -z.
vane_ring_top_z = -vane_gap_below_exit;                 // 베인링 상단
vane_ring_bot_z = vane_ring_top_z - vane_ring_h;         // 베인링 하단
top_plate_bot_z = vane_ring_top_z + col_len;             // 상판 하단 (기둥이 여기서 베인링까지)
top_plate_top_z = top_plate_bot_z + top_plate_t;
foot_z          = -foot_below_exit;                      // 발 바닥
bail_top_z      = foot_z + H_total;                      // 검증용: 베일 팁

vane_ring_od = edf_housing_od + 24;
vane_ring_id = edf_housing_od + 4;
leg_top_r    = vane_ring_od/2;        // 다리 상단 부착 반경 (베인링에서 시작)
leg_bot_r    = foot_circle/2;         // 다리 하단(발) 반경
// ⚠️ 버그 수정(2026-09-13): col_mount_r가 예전엔 edf_housing_od/2+25로 따로 계산돼서
//    vane_ring_od/2(=leg_top_r)보다 13mm나 커버렸음 → 기둥이 베인링 바깥 허공에서 끝나
//    실제로 안 닿는 상태였음. 기둥도 다리와 같은 반경(링 바깥 표면)에서 시작하도록 통일.
col_mount_r  = leg_top_r;             // 상판 위 기둥 부착 반경 = 베인링 바깥 반경 (다리와 동일선상, 45도만 엇갈림)
// ---------- 베인 · 방위 규약 (rev C.1) ----------
// 방위: 베인/서보 = 0°/90°/180°/270° (FWD/LEFT/AFT/RIGHT),  기둥·다리 = 45°/135°/225°/315°
//   ⚠️ 버그 수정(2026-09-17): 예전 legs()는 다리를 +90 계열(=베인과 같은 방위)에 놨었다.
//      그 상태면 다리 뿌리와 베인 서보가 같은 자리를 차지해 물리적으로 충돌한다.
//      다리를 기둥과 같은 +45 계열로 옮겨 45° 엇갈리게 만들었다(하중 경로도 기둥-다리 일직선이 유리).
az_vane = 0;    // 베인·서보 방위 오프셋
az_col  = 45;   // 기둥·다리 방위 오프셋

// 베인 피벗 z: 링의 수직 중앙(= 스파가 링 벽 한가운데를 관통 → 부싱 지지가 제대로 됨).
//   마스터 §4 의 "배기면→베인 피벗 22mm"는 실제로는 "배기면→링 상단"에 해당한다(링 높이 28의 중앙이 피벗).
//   즉 실제 피벗은 배기면 아래 36mm. 제어 모멘트암 계산엔 이 값을 쓸 것.
vane_pivot_z = (vane_ring_top_z + vane_ring_bot_z)/2;
vane_outer_r = vane_ring_id/2 + 3;   // 베인 바깥 끝 — 링 벽 슬롯 안으로 3mm 물려서 하드스톱 역할
vane_span_r  = vane_outer_r - vane_inner_r;                       // 베인 반경 방향 길이
// ±vane_stop_deg 회전 시 베인이 쓸고 지나가는 폭/높이 → 링 벽 슬롯 크기(= 기계 하드스톱)
vane_slot_w  = 2*(vane_chord/2*sin(vane_stop_deg) + vane_thick/2*cos(vane_stop_deg));
vane_slot_h  = 2*(vane_chord/2*cos(vane_stop_deg) + vane_thick/2*sin(vane_stop_deg)) + 0.8;
servo_mount_r = vane_ring_od/2;                      // 보스 웹이 시작하는 반경(= 링 바깥면)
servo_plate_r = servo_mount_r + servo_standoff;      // 서보 장착판 안쪽면 반경
vane_spar_len = servo_plate_r - vane_inner_r;        // Ø3 CF 스파 재단 길이(= 베인 안쪽 끝 ~ 장착판)

edf_clamp_id = edf_housing_od + edf_clamp_gap;  // 클램프 내경 = 실측 외경 + 여유
edf_clamp_z  = edf_clamp_z_from_exit;  // 클램프 높이 — 배기면(z=0) 기준, 실측 몸통 길이(edf_body_len) 안에 들어오는 값
edf_body_top_z = edf_body_len;         // 참고용: EDF 몸통 상단(흡입구 립) z — 검증 echo에 사용
tube_clearance = 0.3;                  // 소켓 구멍 여유 (Ø6mm 탄소관 삽입용, mm)
socket_depth   = 12;                   // 베인링에 뚫는 소켓 구멍 깊이 (mm, 링 높이 28mm 중)

// ---------- 모듈 ----------

module top_plate() {
    // 볼트 플랜지 없는 EDF라 상판엔 흡기 공기 통로용 홀만 뚫음 (마운트는 edf_clamp()가 담당)
    // ⚠️ D1 탄소관(기둥)은 프린트하는 게 아니라 실제 구매품 — 상판엔 관통 소켓 구멍만 뚫고 여기에 접착
    difference() {
        cylinder(h=top_plate_t, r=col_mount_r + 15, center=false);
        // EDF 흡기 통로 홀 — 하우징보다 살짝 크게(공기 흐름 여유, 접촉 없음)
        translate([0,0,-1]) cylinder(h=top_plate_t+2, r=edf_housing_od/2 + 3, center=false);
        // D1 탄소관(기둥) 삽입용 관통 소켓 4개
        for (i=[0:n_cols-1]) {
            a = i*360/n_cols + 45;
            translate([col_mount_r*cos(a), col_mount_r*sin(a), -1])
                cylinder(h=top_plate_t+2, r=col_od/2 + tube_clearance, center=false);
        }
    }
}
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

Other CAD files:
cad/legacy/params.scad
cad/legacy/top_plate.scad
cad/legacy/vane_ring.scad

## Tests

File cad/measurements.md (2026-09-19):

# 실측값 기록

캘리퍼스로 잰 부품 실측값을 여기 적고, `cad/hopper_params.scad`의 `MEASURED` 블록에 반영한 뒤 커밋한다.
값을 바꿀 때마다 이 표도 같이 업데이트할 것 — 나중에 "이 숫자가 어디서 나왔는지" 확인할 유일한 근거다.

| 부품 / 위치 | 측정값 (mm) | 측정 방법 | 측정자 | 날짜 | 비고 |
|---|---|---|---|---|---|
| EDF 외경(앞, 프로펠러쪽) | 71.9 (둘레 226mm 환산) | 줄자로 둘레 측정 후 ÷π | 민찬 | 2026-09-18 | 1차(9/13) 측정 72mm와 오차 0.5mm 이내로 일치 — 재확인 완료. `edf_housing_od`는 72 유지 |
| EDF 외경(뒤, 모터쪽) | 69.9 (둘레 219.5mm 환산) | 줄자로 둘레 측정 후 ÷π | 민찬 | 2026-09-18 | 1차 측정 70mm와 일치. `edf_body_od_min`는 70 유지 |
| EDF 마운트 홀 간격 | N/A | — | — | 2026-09-13 | 볼트 플랜지 없는 제품으로 확인됨(사진 확인) → 클램프 마운트로 설계 전환. 이 항목은 측정 대상 아님 |
| Teensy 보드 가로×세로 | ~~35.5 × 10~~ → **35 × 17 (최종, 2026-09-19)** | 자, 2회 재측정 | 민찬 | 2026-09-19 | 1차(9/18) "세로 10mm"는 측정 오류로 확인 — 재측정 결과 공식 스펙(36×18mm)과 거의 일치. `teensy_w`는 미리보기 전용 치수라 프린트 파츠 형상엔 영향 없음(핀헤더 열 간격 17.78mm는 규격 고정값) |
| 베인(vane) 서보 이어 홀 피치 | **33 (실측 확정)** | 캘리퍼스, SG90 실물(MG90S 대용 — 케이스 규격 동일) | 민찬 | 2026-09-19 | 조사자료 추정값(27.5~28.0)보다 5mm 큼 — `servo_ear_pitch`를 33으로 교체. 마운트판 폭은 이 값에 자동 연동되는 파라메트릭 구조라 CAD 재계산됨 |
| 베인 서보 몸통 길이(반경방향, 축 보스 제외) | **28 (실측 확정)** | 캘리퍼스, SG90 실물 | 민찬 | 2026-09-19 | 조사자료 추정값(22.5)보다 5.5mm 큼 — `servo_body_h`를 28로 교체. 프린트 형상엔 안 쓰이는 클리어런스 참고값(미리보기·echo 전용) |
| 베인 서보 몸통 폭(두께) | **23 (실측 확정)** | 캘리퍼스, SG90 실물 | 민찬 | 2026-09-19 | ⚠️ 정정: 처음엔 "몸통 폭 2.3"을 몸통 긴변(`servo_body_l`)으로 잘못 재해석했었음(2026-09-19 1차 반영). 원래 그대로 ②(두께, `servo_body_w`)로 받는 게 맞음 — 정정 반영. 조사자료 추정값(12.0~12.4)보다 훨씬 큼 |
| 베인 서보 축→가까운 이어홀 거리 | **3 (실측 확정)** | 캘리퍼스, SG90 실물 | 민찬 | 2026-09-19 | ⚠️ 정정: 처음엔 "축은 0.3"을 출력축 지름으로 잘못 재해석했었음. 원래 그대로 ④(축→이어홀 거리, `servo_ear_to_shaft`)로 받는 게 맞음 — 정정 반영. 조사자료 추정값(9.9)보다 훨씬 짧음 → 이어 홀이 출력축 기준 비대칭 배치(−3 / +30)가 돼서 `servo_boss_solid()`의 마운트판 폭 계산도 같이 수정함(양쪽 홀을 전부 덮도록) |
| 베인 서보 몸통 긴변(접선방향) | 미측정 — 22.8 유지(조사자료) | — | — | — | ⚠️ 아직 안 잼. `servo_body_l` 플레이스홀더 유지 (9/19 1차엔 23으로 잘못 반영했다가 위 정정으로 되돌림) |
| 배터리 가로×세로×두께 | ~~34 × 74~~ → **63.5 × 32.5 × 15 (최종, 2026-09-19)** | 자, 3축 전부 재측정 | 민찬 | 2026-09-19 | 1차(9/18)는 2축만 쟀고 오차도 있었음 — 재측정으로 3축 전부 확정, `batt_l/w/h` 교체 |

**상판 두께는 측정 항목 아님** — `cad/print_parts/top_plate.stl`로 3D 프린트할 파츠라 잴 실물이 없다. 마스터 설계 §4에 이미 `top_plate_t = 4mm`로 잡혀 있으니, 그대로 쓸지 강성 보고 바꿀지만 결정해서 `hopper_params.scad`에 반영. (플랜B로 합판 상판을 쓰게 되면 그때만 실측 필요.)

측정할 때 참고:
- 캘리퍼스 0점(zeroing) 먼저 확인.
- 같은 곳을 2번 재서 값이 다르면 셋째 값까지 재고 중간값 사용.
- 표에 없는 항목이 필요하면 행을 추가하고 커밋 메시지에 `[cad]` 태그 붙이기.

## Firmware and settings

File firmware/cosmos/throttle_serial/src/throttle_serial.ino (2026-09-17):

// COSMOS PRJ-01 · DShot 스로틀 시리얼 테스트 스케치
// 시리얼 모니터에 0~100 숫자를 입력하면 그 %만큼 스로틀을 낸다.
//
// 이 폴더의 dshot.h / dshot.cpp는 firmware/reference/SingleRotorUAV/src/에서
// 그대로 복사해온 것이다 — Teensy 4.x 전용 DMA 기반 드라이버라 새로 만들 필요가 없다.
//
// *** 반드시 프로펠러/EDF 팬을 분리한 상태에서만 테스트할 것 ***
//
// 배선: ESC 신호선 → Teensy 핀 8 (DSHOT_PORT_1 이 dshot.cpp에 핀 8로 하드코딩되어 있음)
//       ESC/모터 접지 ↔ Teensy 접지 공통 연결 필수
//       ESC의 BEC 5V 출력은 Teensy에 연결하지 않는다 (배터리로 직접 전원 공급)

#include "dshot.h"

DShot motors(1); // 이 스케치에서는 출력 1개만 사용 (DSHOT_PORT_1)

const unsigned long FAILSAFE_MS = 2000; // 이 시간 안에 새 입력이 없으면 자동으로 0%
unsigned long lastCommandTime = 0;
int currentThrottlePct = 0;

void setup() {
  Serial.begin(115200);
  while (!Serial && millis() < 3000) {}

  motors.setup();
  motors.setConfig(DSHOT_PORT_1, DSHOT_CMD_3D_MODE_OFF);
  motors.armMotors(); // 약 50ms 소요 — ESC에 정지 신호를 반복 전송해서 시동을 건다

  Serial.println("=== DShot 준비 완료 ===");
  Serial.println("*** 프로펠러/EDF 팬이 분리되어 있는지 다시 한 번 확인! ***");
  Serial.println("시리얼 모니터에 0~100 숫자를 입력하면 그 %로 스로틀이 걸립니다.");
  Serial.println("2초 동안 새 입력이 없으면 안전을 위해 자동으로 0%로 내려갑니다.");

  lastCommandTime = millis();
}

void loop() {
  if (Serial.available()) {
    int pct = Serial.parseInt();
    if (pct >= 0 && pct <= 100) {
      currentThrottlePct = pct;
      lastCommandTime = millis();
      Serial.print("Throttle -> ");
      Serial.print(pct);
      Serial.println("%");
    }
  }

  // failsafe: 일정 시간 새 명령이 없으면 자동으로 0%
  if (millis() - lastCommandTime > FAILSAFE_MS) {
    currentThrottlePct = 0;
  }

  // DShot 값 인코딩: 0=정지, 48~2047=실제 스로틀 (0~47은 명령어로 예약됨)
  // control.cpp의 실제 사용 예시(motors.write(index, 47 + throttle, 1))를 참고해 계산
  uint16_t dshotValue = (currentThrottlePct == 0) ? 0
                        : map(currentThrottlePct, 1, 100, 48, 2047);

  motors.write(DSHOT_PORT_1, dshotValue, DSHOT_TLM_NONE);

  delay(2); // DShot 갱신 주기 (너무 빠르게 반복 호출하지 않도록)
}

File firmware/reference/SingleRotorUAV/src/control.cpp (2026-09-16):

#include "control.h"

DShot motors(2); 

const uint16_t Control::servo_pins[] = { SERVO_1_PIN, SERVO_2_PIN, SERVO_3_PIN, SERVO_4_PIN };

/* Interrupts to read RC control inputs */
const uint16_t rc_pins[] = {18, 19, 23, 1};
volatile uint16_t rc_input[4];
volatile elapsedMicros rc_input_timer[4];

void rc_input_isr0(){
    if( digitalReadFast(rc_pins[0]) == HIGH )
        rc_input_timer[0] = 0;
    else 
        rc_input[0] = rc_input_timer[0];
}

void rc_input_isr1(){
    if( digitalReadFast(rc_pins[1]) == HIGH )
        rc_input_timer[1] = 0;
    else 
        rc_input[1] = rc_input_timer[1];
}

void rc_input_isr2(){
    if( digitalReadFast(rc_pins[2]) == HIGH )
        rc_input_timer[2] = 0;
    else 
        rc_input[2] = rc_input_timer[2];
}

void rc_input_isr3(){
    if( digitalReadFast(rc_pins[3]) == HIGH )
        rc_input_timer[3] = 0;
    else 
        rc_input[3] = rc_input_timer[3];
}

Control::Control(){
    // Allocate four servo objects
    servos = new Servo[4];

    // Allocate DShot object, with two outputs; pin 8 and 9 (hardcoded)
    // motors = new DShot(2);
}


void Control::init( )
{
    
    attachInterrupt( rc_pins[0], rc_input_isr0, CHANGE );
    attachInterrupt( rc_pins[1], rc_input_isr1, CHANGE );
    attachInterrupt( rc_pins[2], rc_input_isr2, CHANGE );
    attachInterrupt( rc_pins[3], rc_input_isr3, CHANGE );

    // Configure servo motors
    for( uint8_t i = 0; i < 4; i++){
        // Configure min/max PWM for servos
        servos[i].attach( servo_pins[i], SERVO_MIN_TIMING, SERVO_MAX_TIMING);

        // Centre all servos
        write_servo( i , 0 ); // 0 degress
    }

    /* Configure the DSHOT outputs */
    motors.setup();

    // Configure BLDC motor drivers (ESC)
    motors.setConfig( DSHOT_PORT_1, DSHOT_CMD_SPIN_DIRECTION_2 ); // Depending on soldering of wires, this can be changed.
    motors.setConfig( DSHOT_PORT_1, DSHOT_CMD_3D_MODE_OFF );

    motors.setConfig( DSHOT_PORT_2, DSHOT_CMD_SPIN_DIRECTION_1 ); // Depending on soldering of wires, this can be changed.
    motors.setConfig( DSHOT_PORT_2, DSHOT_CMD_3D_MODE_OFF );

    delay(1000);
    /* Arm all DSHOT ports / ESCs */
    motors.armMotors();
}

void Control::set_servo_offsets( int16_t * offsets ){
    for (uint8_t i = 0; i < 4; i++)
    {   
        // Serial.println(offsets[i]);
        servo_offset[i] = offsets[i];
    }
}

void Control::write_motor( uint8_t index, uint16_t throttle ){

    if( throttle > 2000 )
        throttle = 2000;

    // Write motor throttle, and dont request telemetry = 0;
    motors.write( index, 47 + throttle, 1 );

}


void Control::write_servo( uint8_t index, float angle )
{
    // Scale angle, to get higher resolution on the map
    int32_t temp = (int32_t)(angle*1000);

    // Transform angle to PWM timing
    uint16_t timing = map( temp, -30*1000, 30*1000, SERVO_MIN_TIMING, SERVO_MAX_TIMING);

    // Write servo signal
    servos[index].writeMicroseconds(timing + servo_offset[index] );
}

void Control::write_servo_ms( uint8_t index, uint16_t ms ){
    servos[index].writeMicroseconds( ms );
}


void Control::read_control_input(){

    uint16_t input1 = constrain( rc_input[0], 1100, 1900);
    float z_ref = ((float)map(input1, 1100, 1900, 0, (uint16_t)(SETPOINT_MAX_Z*1000)))/1000;

    /* uint16_t input2 = constrain( rc_input[1], 1100, 1900);
    float roll_ref = ((float)map(input2, 1100, 1900, -(uint16_t)(SETPOINT_MAX_ROLL*1000), (uint16_t)(SETPOINT_MAX_ROLL*1000)))/1000;

    uint16_t input3 = constrain( rc_input[2], 1100, 1900);
    float pitch_ref = ((float)map(input3, 1100, 1900, -(uint16_t)(SETPOINT_MAX_PITCH*1000), (uint16_t)(SETPOINT_MAX_PITCH*1000)))/1000; */

    if( z_ref == 0 ){
        set_max_throttle(0); // Kill throttle
        reset_integral_action();

    }else{
        set_max_throttle(MOTOR_MAX_DSHOT);
    }

    // Only update setpoint if takeoff has been commanded
    // Do not interfere with the landing sequence
    if( status == CONTROL_STATUS_FLYING ){
        set_reference( SETPOINT_Z, z_ref );
    }
}


void Control::control_hover( float roll, float pitch, float yaw, float gx, float gy, float gz, float z, float vz ){
    
    Matrix<5,1> output; // Output vector
    Matrix<9,1> error; // State error vector
    Matrix<5,9> K = K_hover; 
    Matrix<9,1> ref = SP_hover;

    // Add the output of the position controller to the hover setpoint
    ref(0) += U_pos(0);
    ref(1) += U_pos(1);

    // Integral action for altitude (z)
    float error_z = ref(6) - z; 

    // If the throttle output is less than the allowed maximum, or the z error is lower than 0, compute the integral
    if( data.dshot < max_throttle || error_z < 0 ){

        // If the drone is landing, change how the integral behaves. 
        if( status == CONTROL_STATUS_LANDING ){
            if( z < 0.01 ){ // 10mm above ground
                // We have landing, stop engines
                status = CONTROL_STATUS_STATIONARY;
            }
            else if( z < 0.2 ){
                error_z = error_z * 1.2; // Reduce integral fast
            }else{
                error_z = error_z * 0.2;
            }
            
        }
        error_integral_z += error_z * CONTROL_LOOP_INTERVAL;
    }

    // Load states into state-vector (int_z = integral term)
    X = {roll, pitch, yaw, gx, gy, gz, z, vz, 0};

    error = ref - X;
    error(8) = error_integral_z; // Insert integral term into the state-error vector

    // Special case for yaw:
    if( error(2) > PI )
        error(2) -= TWO_PI ;


    // If commanded to land, remove P-control from altitude and reduce integral-control
    if( status == CONTROL_STATUS_LANDING ){
        K(4,6) = 0;          // Remove P-gain
    }

    // Run Controller
    output = K * error; 

    // Filter servo outputs, to remove unwanted spikes
    U(0) = RateLimit( output(0), U(0), 0.3 );
    U(1) = RateLimit( output(1), U(1), 0.3 );
    U(2) = RateLimit( output(2), U(2), 0.3 );
    U(3) = RateLimit( output(3), U(3), 0.3 );

    // Saturate outputs to reduce control bleps
    U(0) = Limit( U(0), -20, 20 );
    U(1) = Limit( U(1), -20, 20 );
    U(2) = Limit( U(2), -20, 20 );
    U(3) = Limit( U(3), -20, 20 );

    U(4) = output(4);

}


void Control::set_reference( control_setpoint_t id, float value ){

    switch( id ){
        case SETPOINT_X: SP_pos(0) = value; break;
        case SETPOINT_Y: SP_pos(1) = value; break;
        case SETPOINT_Z: SP_hover(6) = value; break;
        case SETPOINT_ROLL: SP_hover(0) = value; break;
        case SETPOINT_PITCH: SP_hover(1) = value; break;
        case SETPOINT_YAW: SP_hover(2) = value; break;
    }

}
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

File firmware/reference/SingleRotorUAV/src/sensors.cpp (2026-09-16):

#include "sensors.h"

Sensors::Sensors(void){
    imu = new BNO080(IMU_CS_PIN, IMU_WAK_PIN, IMU_INT_PIN, IMU_RST_PIN);
    flow = new PMW3901(FLOW_CS_PIN);
    lidar = new VL53L1X(); // I2C thus no CS
}

void Sensors::init(void){

    // Disable all SPI devices  before setup
    pinMode( IMU_CS_PIN, OUTPUT );
    pinMode( FLOW_CS_PIN, OUTPUT );
    digitalWrite( IMU_CS_PIN, HIGH );
    digitalWrite( FLOW_CS_PIN, HIGH );

    delay(100);

    // Initiate flow sensor
    if ( flow->begin() ) {
        flow->setLed( HIGH );
        status.flow = STATUS_READY;
    }else{
        status.flow = STATUS_FAILED_SETUP;
    }

    delay(100);

    // Init IMU
    if( imu->beginSPI() ){
        // Continous sample of sensors
        imu->enableGyro(5);  // 5ms / 200hz
        imu->enableLinearAccelerometer(5);  // 5ms / 200hz
        imu->enableRotationVector(5); // 5ms / 200Hz
        status.imu = STATUS_READY;
    }else{
        status.imu = STATUS_FAILED_SETUP;
    }

    delay(100);


    // Start I2C bus 1
    Wire1.begin();
    Wire1.setClock(400000); // use 400 kHz I2C

    // Set lidar to use I2C bus 1
    lidar->setBus(&Wire1);

    if ( lidar->init() ){
        lidar->setTimeout(0); // A value of 0 disables the timeout = Non-blocking
        lidar->setDistanceMode(VL53L1X::Medium); // Up to 2.9 meters
        lidar->setMeasurementTimingBudget(33000);
        lidar->startContinuous(33);

        status.lidar = STATUS_READY;
    }else{
        status.lidar = STATUS_FAILED_SETUP;
    }
}

void Sensors::run_estimator(){

    /* ---- Sensor processing ---- */
    float p[3] = {0}; // Position vector (z body to world)
    float v[3] = {0}; // Velocity vector (vx, vy to world)
    float a[3] = {0}; // Acceleration vector (ax, ay, az to world)

    // Rotate lidar measurement to world frame
    p[2] = data.z;
    rotate_to_world( p );

    // Perform gyrocompensation on flow and rotate to world frame.
    v[0] = data.vx * p[2] + data.gy * p[2];
    v[1] = data.vy * p[2] - data.gx * p[2]; 
    rotate_to_world( v );

    // Rotate acceleration to world frame
    a[0] = data.ax; a[1] = data.ay; a[2] = data.az;
    rotate_to_world( a );


    /* ---- Estimation ---- */
    // Fill input vector with acceleration
    H.Fill(0);
    Z.Fill(0);
    U = {a[0], a[1], a[2]};

    // Fill measurement vector with data
    if( data.status.pos == 1 ){
        H(0,0) = 1; H(1,1) = 1;
        Z(0) = data.x;
        Z(1) = data.y;
    }

    if( data.status.lidar == 1){
        H(2,2) = 1;
        Z(2) = p[2]; // p[2]: z
    }

    if( data.status.flow == 1){
        H(3,3) = 1; H(4,4) = 1;
        Z(3) = v[0]; // vx
        Z(4) = v[1]; // vy
    }

    // Prediction, based on previous state and current input
    Xpre = A*X + B*U; 

    // Update prediction with update using measurements 
    X = Xpre + Kf*(Z - H*Xpre); 
    
    // Fill estimate struct with values (for telemetry and stuff)
    estimate.x = X(0);
    estimate.y = X(1);
    estimate.z = X(2);
    estimate.vx = X(3);
    estimate.vy = X(4);
    estimate.vz = X(5);

    // Reset status (measurements has been used!)
    data.status.flow = 0;
    data.status.lidar = 0;
    data.status.imu = 0;
    data.status.pos = 0;
}

void Sensors::sample_imu(){

    uint16_t report_ID;
    float accel[3]; 

    while ( report_ID = imu->getReadings() ) {
        // Read Attitude estimate
        // roll and pitch are flipped because of IMU orientation
        if( report_ID == SENSOR_REPORTID_ROTATION_VECTOR ){
            data.roll   = imu->getPitch();  // Radians 
            data.pitch  = -imu->getRoll();   // Radians
            yaw_raw     = imu->getYaw();    // Radians
            data.yaw    = rotate_yaw( yaw_raw );  
        }

        // Linear acceleration is gravity componsated (but still measured in body frame)
        // x and y are flipped because of orientation of IMU
        if( report_ID == SENSOR_REPORTID_LINEAR_ACCELERATION ){
            
            data.ax = LPF( imu->getLinAccelY(), data.ax, 1 ) ; // Filter coefficient 1 = No lowpass
            data.ay = LPF( -imu->getLinAccelX(), data.ay, 1 ) ;
            data.az = LPF( imu->getLinAccelZ(), data.az, 0.8 );

        }

        // Read Raw Gyro data 
        // gx and gy are flipped because of IMU orientation
        if( report_ID == SENSOR_REPORTID_GYROSCOPE ) {
            data.gx = LPF( imu->getGyroY(), data.gx, 0.8 ); // Radians / second
            data.gy = LPF( -imu->getGyroX(), data.gy, 0.8 ); // Radians / second
            data.gz = LPF( imu->getGyroZ(), data.gz, 0.8 ); // Radians / second
        }

        data.status.imu = 1;

    }
}

void Sensors::sample_flow()
{
    static uint32_t last_sample;
    int16_t dx, dy;
    float ofx, ofy;

    float dt = (micros() - last_sample);
    dt = dt/1000000;
    
    last_sample = micros();
    
    // Here dy and dx are flipped, to match orientation of IMU (which is placed to align with the body frame)
    flow->readMotionCount( &dy, &dx );

    // Convert change in pixels to unitless velocity 1/s
    ofx = ((float)dx / dt ) / PMW3901_FOCAL; // Focal length (in px) found experimentally
    ofy = ((float)dy / dt ) / PMW3901_FOCAL;

    // Return the unitless velocity, which can be scaled by height above ground (z)
    data.vx = ofx; // pixels / second
    data.vy = ofy; // pixels / second

    data.status.flow = 1;
}

void Sensors::sample_lidar(){

    float zb;

    if( lidar->dataReady() ){

        uint16_t value = lidar->read(false); // Non blocking

        // Altitude measured in body frame.
        zb = ((float)value)/1000 - SENSOR_LIDAR_OFFSET; // Convert to meters

        // Sanity check
        if(zb < 0 )
            zb = 0;

        // Rotate altitude to world frame
        // z = zb * cos( data.pitch ) * cos( data.roll );

        data.z = LPF( zb , data.z, 1 );

        data.status.lidar = 1;

    }

}

float Sensors::LPF( float new_sample, float old_sample, float alpha ){
    return ((alpha * new_sample) + (1.0-alpha) * old_sample);  
}



void Sensors::set_origin(){
    yaw_origin = yaw_raw;

    X.Fill(0);
}


void Sensors::update_pos( float x, float y ){

    data.x = x;
    data.y = y;

    data.status.pos = 1;
}

// Rotate yaw to align with origin / home
float Sensors::rotate_yaw( float yaw ){

    float rotated = yaw - yaw_origin;

    if( rotated > PI )
        rotated -= TWO_PI;
    else if( rotated < -PI )
        rotated += TWO_PI;
    
    return rotated;

}
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

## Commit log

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2026-09-17 [docs] AGENTS.md를 정본으로 통일, 레포 정합성 점검·수복
    - AGENTS.md ↔ CLAUDE.md를 수동으로 각각 유지하다 Codex용 find-replace로
    claude.ai 링크가 Codex.ai로 깨지는 사고 발견 → AGENTS.md를 유일한 정본으로,
    CLAUDE.md는 거기로 가는 1페이지 안내판으로 축소
    - AGENTS.md의 "확정된 방향"에 남아있던 rev A 스펙(70mm EDF·6S·Pixhawk)이
    실제 rev C 결정과 모순되던 것 정리 — 마스터 설계도로 포인터만 남김
    - 상태 로그가 "완료"로 적어뒀던 파일 중 실물이 없는 것 발견:
    cad/print_parts/의 STL 7종(export 안 됨), 옛 modelling-notes-ch3.md(유실),
    COSMOS_면접_예상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
    [hopper_params.scad, params.scad, top_plate.scad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]
2026-09-18 main 직접 커밋 금지 규칙 + 의존성 고정·CI·작업 실행기 (#1)
    * [docs] 브랜치·PR 규칙 추가 — main 직접 커밋 금지
    작업은 항상 브랜치에서 하고 PR로 올린다. 리뷰어는 junwonkim07(부장)으로
    지정하고, 승인 전에는 머지하지 않는다. 머지 권한은 김준원(junwonkim07)·
    김민찬(MINBBBB1201) 두 명에게만 있다 — 본인 PR도 직접 머지 금지.
    이전 규칙("폴더가 팀별로 나뉘어 있으니 main 직접 커밋")의 비용은 충돌이
    아니라, 깨진 코드가 곧바로 모두의 git pull에 실려 간다는 점이었다.
    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
2026-09-18 [docs][cad] rev C.1 확정: 아비오닉스·배선·기계통합 + 소프트웨어 로드맵/제어파이프라인 (#2)
    * [docs][cad] rev C.1 확정: 아비오닉스·배선·기계통합 + 소프트웨어 로드맵/제어파이프라인
    기구·전자팀 (Claude Code):
    - docs/design/01-avionics-integration-final.md 신설 — Teensy 4.0 핀맵 확정
    및 스톡 펌웨어 충돌 검증, 전원계통·전류예산, 빵판/만능기판 배치(홀 좌표),
    하네스 목록, 기계 통합(장비선반), CG 재계산, 조립/브링업 절차
    - cad/hopper_params.scad rev C.1 — 장비선반(배터리/아비오닉스) 도입, 서보
    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
    [cosmos-avionics.kicad_sch, hopper_params.scad]
2026-09-18 [docs] 브랜치·PR 규칙을 최초 확정본(a91a715)으로 원복 (#3)
    PR #1 머지 직전에 MINBBBB1201이 올린 c3ab1dd("머지 권한 정책 완화 + 부장 오기 수정")가
    작성자(junwonkim07) 확인 없이 규칙 본문을 바꾼 채 머지됐다. 규칙 섹션(AGENTS.md)과
    README의 머지 정책 항목을 원래 내용으로 되돌린다:
    - PR 리뷰어는 junwonkim07, 승인(Approve) 전에는 머지하지 않는다
    - 머지 가능자는 김준원·김민찬 둘뿐이고, 본인 PR도 스스로 머지하지 않는다
    - AI 에이전트는 PR 생성·CI 통과까지만, 머지는 매번 별도로 확인받는다
    PR #2의 다른 내용(문서 맵·CAD·설계 문서)은 건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
2026-09-18 [docs][cad] Revert "rev C.1 확정: 아비오닉스·배선·기계통합 + 소프트웨어 로드맵/제어파이프라인 (#2)" (#4)
    This reverts commit e954e47a. PR #2는 리뷰·승인 없이 셀프 머지됐다(작성자 MINBBBB1201,
    머지자 동일). 규칙(AGENTS.md "작업 규칙 — 브랜치·PR")대로 부장 승인 뒤 다시 PR로 올린다.
    원 커밋 내용은 히스토리(e954e47)에 그대로 남아 있으므로 복구는 언제든 가능하다.
    [cosmos-avionics.kicad_sch, hopper_params.scad]
2026-09-18 [infra] CODEOWNERS 추가 — 운영 인프라 파일은 junwonkim07 승인 필수 (#5)
    브랜치·PR 규칙(AGENTS.md·README.md·CLAUDE.md), CI(.github/), 의존성 고정(sim/requirements.txt),
    작업 실행기(tasks.py), .gitignore를 코드 오너 junwonkim07에 귀속. main 룰셋의
    "Require review from Code Owners"와 결합해 이 파일들은 오너 승인 없이는 머지되지 않는다.
2026-09-19 [docs] 설명회 대본의 비행 컨트롤러 서술을 rev C(Teensy)로 정정 (#8)
    대본 슬라이드 4가 "실제로 이 제어를 구현할 하드웨어는 픽스호크(Pixhawk) 4 ... 아두파일럿을
    올려서 쓸 겁니다"로 되어 있는데, 저장소 확정안과 다르다.
    - Pixhawk는 rev A 스펙이고 이미 폐기됐다. docs/design/00-hopper-master-design.md:
    "A | 70mm EDF · 6S · Pixhawk · ... | 폐기 — 제작 전, 비용·엔지니어링 부담으로 스케일 다운"
    - 현행 rev C는 Teensy 4.0 + BNO085 + 양방향 DShot ESC이고, BOM 파일명 자체가
    BOM-revC-teensy.md 다. 이미 만들어 둔 firmware/cosmos/ 도 전부 Teensy 전제다.
    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
2026-09-19 [infra] uv 워크스페이스 전환 + 작업 그래프·입력 해시 캐시 (#6)
    * [infra] uv 워크스페이스 전환 + 작업 그래프·입력 해시 캐시
    의존성 관리를 uv 워크스페이스로 옮기고, tasks.py를 "작업 그래프 + 입력 해시 캐시"
    구조로 다시 썼다. 둘의 역할을 분리한 것 — 무엇을 설치할지는 uv(pyproject+lock)가,
    무엇을 어떤 순서로 실행할지는 tasks.py가 안다.
    무엇이 바뀌나
    - pyproject.toml(루트) / sim/pyproject.toml / uv.lock 추가.
    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
2026-09-19 [sim] 커넥톰 제약 정책망 트랙 추가 (sim/connectome/) (#9)
    * [sim] 커넥톰 제약 정책망 트랙 추가 (sim/connectome/)
    초파리 커넥톰의 배선을 PPO 정책망의 '연결 구조'로 고정하고 가중치만 학습하는
    비교군을 추가한다. 확정된 방향이 아니라 시뮬레이션 전용 확장 트랙이고, 메인
    트랙(PID/LQR vs RL)을 대체하지 않는다 — 비교군을 하나 더 얹는 것이다.
    무엇이 들어왔나
    - graph.py 서브그래프 자료구조 + 정합성 검증 + 스펙트럼 반경 정규화
    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
2026-09-19 [docs][cad] rev C.1 복구 — 리뷰 절차 거쳐 재병합 요청 (#7)
    * [docs][cad] rev C.1 확정: 아비오닉스·배선·기계통합 + 소프트웨어 로드맵/제어파이프라인 (#2)
    - cad/hopper_params.scad rev C.1 — 장비선반(배터리/아비오닉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
    [cosmos-avionics.kicad_sch, hopper_params.scad]
2026-09-19 [infra] CODEOWNERS 제거 — 자동 리뷰 요청 중단 (#12)
    main 룰셋에서 "Require review from Code Owners"는 이미 꺼져 있어서 이 파일은
    머지를 막지는 않았다. 다만 해당 경로를 건드리는 PR마다 오너에게 리뷰 요청이
    자동으로 걸려서, 실제로 필요하지도 않은 리뷰 알림만 쌓였다.
    리뷰 승인 없이 머지하기로 정리하면서 파일을 지운다. main 보호(PR 경유 +
    CI 초록불)는 그대로 유지된다.
2026-09-19 [sim] params.yaml Kf 플레이스홀더 역산 보정 (0.27N -> 9.9N @100%) (#10)
    기존 Kf=3.0e-8은 100% 스로틀에서 추력 0.27N — 64mm급 EDF 실제 정적추력(8~12N)의
    1/37 수준이었다. 5초간 최대 토크를 다 써도 5.8도밖에 못 바꿔서, 초기 교란(최대 17도)
    앞에서 PID든 RL이든 전부 실패해 비교 실험 자체가 성립하지 않는 상태였다.
    PR #9(sim/connectome-policy) 리뷰 중 발견 — 해당 PR과 무관하게 실재하던 값 오류라
    별도로 분리해서 올린다. Kf=1.1e-6으로 바꾸면 100%에서 9.9N(목표 중간값)이 나온다.
    여전히 PLACEHOLDER — 실험 A(EDF 추력곡선 실측) 나오면 반드시 교체할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
2026-09-19 [fw] Arduino IDE → PlatformIO 전환 + imu_test 컴파일 버그 수정 (#11)
    오늘 SW팀 개발환경이 VSCode+PlatformIO로 바뀐 것을 반영:
    - firmware/cosmos/imu_test/, throttle_serial/ 각각 독립 PlatformIO 프로젝트로
    재구조화(platformio.ini + src/), pio run으로 실제 빌드 검증
    - 그 과정에서 imu_test.ino의 진짜 컴파일 오류 발견·수정 — `BNO080 imu;`가 없는
    기본 생성자를 호출하고 있었음(BNO080.h엔 4-인자 SPI용 생성자만 존재). 이전엔
    아무도 실제로 컴파일해본 적이 없어서 안 걸렸던 버그(AGENTS.md에 "업로드 아직"
    으로만 적혀 있었음). BNO080(255,255,255,255)로 수정 — I2C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
    [imu_test.ino, throttle_serial.ino]
2026-09-19 [fw] imu_test I2C → SPI 전환 — 핀 18/19 RC 수신기와 충돌 회피 (#13)
    병합된 imu_test.ino가 I2C(SDA=18,SCL=19)로 BNO085를 초기화하고 있었는데,
    그 두 핀은 01-avionics-integration-final.md §2.2 확정 핀맵에서 RC 수신기
    CH1(스로틀)·CH2(롤)로 이미 예약돼 있다. 지금 IMU 단독 테스트는 문제없지만
    나중에 RC까지 붙이는 통합 펌웨어에서 배선을 다시 다 뜯어야 하는 상황이라,
    지금 SPI로 전환한다(설계도가 원래 선택한 방식).
    - BNO080 생성자에 CS=10, WAK/PS0=22, INT=21, RST=20 전달
    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
2026-09-21 [docs] 전체 타임라인 한 장 요약 추가 (TIMELINE.md) (#14)
    부장 요청 — 소프트웨어팀·엔지니어링팀 타임라인을 한 파일에서 보기 쉽게.
    - Mermaid 간트차트(GitHub이 그대로 렌더): 4개 트랙(공통/엔지니어링/소프트웨어/
    시험·발표), 완료(회색)·진행(파랑)·병목(빨강) 색 구분, 오늘 위치 마커,
    TC-5 비교와 최종 발표를 마일스톤으로
    - 지금까지 한 것 표(증거 PR 번호 포함) + 남은 것 팀별 표(완료 판정 기준 포함)
    - 현재 병목 3개 명시: ①실험A 추력곡선 미실시(Kf 미실측이라 RL 결과를 읽으면
    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
2026-09-22 [docs] 머지된 PR 상태와 운영 규칙을 README에 반영 (#15)
    * [docs] 최근 PR 운영 규칙을 README에 반영
    * [docs] 머지된 PR 상태와 운영 권한 정리
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2026-10-15 [fw] IMU I2C 4선 브링업 스케치 추가 + SPI 배선 주석 MOSI/MISO 정정 (#18)
    2026-10-15 실물에서 BNO085가 I2C 0x4B로 인식되고 자세값이 나오는 것을 확인한
    스케치를 imu_test_i2c로 분리했다. imu_test(SPI)의 배선 주석은 GY-BNO08X 실크
    기준으로 ADDR/MOSI→11, SDA/MISO/TX→12로 바로잡았다(이전엔 뒤바뀌어 있었음).
2026-10-15 [docs] 오픈소스 RL 환경 조사 + PyFlyt 제트 베인 가능 여부 확인 (#22)
    EDF 1개 + 제트 베인 4개 구성에 바로 쓸 오픈소스 RL 환경은 없고, 같은 계열 두
    프로젝트가 RL에서 고전 제어로 돌아간 기록을 정리했다. PyFlyt LiftingSurface는
    링크 속도에서 바람장만 빼서 공기 속도를 계산해 제트 베인을 그대로 표현하지
    못한다는 점을 소스로 확인해 03 문서 §8-1에 결과를 연결했다.
2026-10-16 [fw] DShot 벤치 펌웨어 안전 로직 재작성 (arm 게이트·상한·램프·워치독) (#19)
    기존 throttle_serial은 Serial.parseInt()가 줄바꿈 뒤 최대 1초 블로킹하면서
    그동안 DShot 프레임이 끊기고, 남은 '\n'을 0으로 읽어 목표를 지웠다. 상한도 없어
    DShot 2047까지 바로 낼 수 있었다.
    - 비블로킹 줄 파서, DShot 1 kHz 연속 출력
    - arm 명령 전에는 출력 0, arm은 스로틀 0일 때만
    - 상한 DShot 600(01-avionics §2.5-6), 초과 입력은 거부
    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
2026-10-16 [docs] 지금 할 일 단일화, 팀별 PRD·착수 초안, ship-issue 작업 순서, AGENTS.md 재정리 (#25)
    * [docs] "지금 할 일"을 학습 안내 표 하나로 통일 (10/16 기준)
    README가 서로 다른 시점의 할 일 문서 세 개를 나란히 가리켜, 부원이 무엇을
    따라야 할지 알 수 없었다. 학습 안내에 10/16 기준 "지금 할 일" 표를 새로 두고
    README·2주차 활동표·개인별 주간표·타임라인이 모두 그 표를 가리키게 했다.
    IMU 업로드 성공(10/15), DShot 안전 펌웨어 머지, 이슈 #21·#24를 반영하고
    타임라인 병목을 갱신했다(9/20 기록은 보존).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
2026-10-17 [infra] 작업 이슈 양식에 상위 PRD 칸 추가 (#81)
    task.yml 맨 앞에 입력 칸 "상위 PRD"(id: parent-prd)를 넣었다.
    웹 양식으로 만든 작업 이슈에도 PRD 번호가 본문 `### 상위 PRD` 칸에 남는다.
    GitHub 이슈 양식 문법에는 상위 이슈(sub-issue)를 정하는 키가 없다.
    그래서 칸 설명에 이슈를 만든 뒤 PRD에 잇는 방법 두 가지를 적었다.
    PRD가 아닌 작업도 이 양식을 쓰므로 필수 칸으로 두지 않았다.
    Refs #54
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2026-10-18 [infra] ship.py에 작업 이슈를 상위 PRD의 sub-issue로 잇는 link 명령 추가 (#113)
    * [infra] ship.py에 작업 이슈를 상위 PRD의 sub-issue로 잇는 link 명령 추가
    `python ship.py link <이슈 번호>`는 이슈 본문의 `### 상위 PRD` 칸에서
    `#<번호>`를 읽고, 그 PRD의 sub-issue로 잇는다(#79에서 차장이 고른 선택지 3).
    - gh의 `issue edit --add-sub-issue`가 아니라 `gh api`로 REST를 부른다.
    그 옵션은 gh 2.94.0(2026-06)에 처음 들어갔고, 부원 PC의 gh는 더 오래됐을 수 있다.
    - 빈 칸, `_No response_`, `없음`, 칸 없음: 잇지 않고 알린다(종료 코드 0).
    - 형식 오류, 번호 여러 개, 자기 자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
2026-10-18 [infra] ship.py 상위 PRD 칸이 #26번을 읽고 org/repo#26은 거르게, wt 출력 순서와 파일 지도 고침 (#146)
    * [infra] 상위 PRD 칸에서 #26번을 읽고 org/repo#26은 읽지 않음
    parent_prd()는 번호를 `#(\d+)\b`로 찾았다. 파이썬 3의 str 정규식에서 `\b`는
    한글을 단어 글자로 본다. 그래서 `#26번`, `#26의 하위 작업`에서 번호를 찾지 못하고
    "번호가 없다"고 알렸다. 또 `someorg/otherrepo#26`을 이 저장소의 #26으로 읽고
    PRD #26 아래로 이었다(#133).
    - ship.py: 정규식 ISSUE_REF `(?<![\w/.-])#([0-9]+)`를 쓴다. `#` 앞에
    글자, `/`, `.`, `-`가 있으면 읽지 않는다. 번호 뒤의 글자는 보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
2026-10-18 [docs] AGENTS.md 김무결 GitHub 아이디와 §작업 순서 8의 사람 몫 예를 고침 (#154)
    * [docs] AGENTS.md 팀 표의 김무결 GitHub 아이디를 IfCollie126으로 고침
    팀 표의 `ifmugyeol2011-commits`는 GitHub에 없는 계정이다
    (`gh api users/ifmugyeol2011-commits` → 404). 표로 assignee를 고르면
    `gh issue create --assignee`가 실패한다(§핵심 규칙 9).
    `IfCollie126`으로 바꾼 근거:
    - 이름 Mugyeol Kim, 계정 생성 2026-10-17T02:51:21Z, user id 343783280.
    - #90, #98의 assignee가 이 계정이다. #90 지정은 #71이 옛 아이디를
    적은 지 15분 뒤(10/17 03:45)이고, 지정 기록의 id도 343783280이다.
    - 조직 멤버 9명 중 M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
2026-10-18 [infra] firmware matrix 결과를 모으는 firmware — 전체 job 추가 (#158)
    * [infra] firmware matrix 결과를 모으는 firmware — 전체 job 추가
    main 룰셋이 firmware 빌드를 required check로 요구하지 않는다(#103).
    matrix 체크 이름은 프로젝트마다 하나씩이라, 룰셋에 하나씩 넣으면
    프로젝트를 더하거나 뺄 때마다 룰셋도 고쳐야 한다.
    - ci.yml에 job firmware-all(name "firmware — 전체")을 더했다.
    needs: [firmware], if: always()로 돌고, needs.firmware.result가
    success가 아니면 실패한다.
    - if: always()가 없으면 firmware가 실패할 때 이 job은 skipped가 되고,
    GitHub은 skipped job을 "Succes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
2026-10-18 [infra] ship.py review가 PR·이슈 기록을 리뷰어에게 표준 입력으로 넘김 (#175)
    * [infra] ship.py review가 PR·이슈 기록을 리뷰어에게 표준 입력으로 넘김
    Codex 리뷰어는 `codex exec --sandbox read-only`로 돈다. 이 샌드박스는
    네트워크를 막아서 리뷰어가 `gh pr view`·`gh issue view`로 근거를 읽지
    못했다(#167).
    ship.py review가 리뷰 전에 gh로 아래 기록을 읽어 표준 입력으로 넘긴다.
    - 이 브랜치의 PR(본문, 댓글, 커밋 날짜)
    - 그 PR이 닫는 이 저장소 이슈(본문, 댓글)
    - 두 본문이 가리키는 이 저장소 `#번호` 기록. 한 단계만, 최대 20개
    리뷰 요청 문장(REVIEW_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
2026-10-18 [infra] PRD 이슈에서 바로 작업하지 않고, 이해 먼저 댓글을 확인하게 ship-issue 순서 보강 (#55)
    * [infra] ship.py wt가 PRD 이슈에서 작업 이슈 안내를 출력하고 멈춘다
    한 PRD를 여러 명이 맡으면 PRD 번호로 만든 브랜치가 겹친다(예: 두 사람 모두 cad/26).
    라벨 prd가 붙은 이슈에서는 worktree와 브랜치를 만들지 않고, 작업 이슈를 만드는
    명령(gh issue create --parent)을 출력한 뒤 exit 1로 끝낸다.
    Refs #52
    * [docs] PRD 아래 사람별 작업 이슈와 "이해 먼저" 확인을 작업 순서에 넣는다
    - AGENTS.md §작업 순서 1·2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
2026-10-18 [infra] CAD 검증 echo를 tasks.py cad 작업으로 check와 CI에서 돌림 (#180)
    * [infra] CAD 검증 echo를 tasks.py cad 작업으로 check와 CI에 넣음
    hopper_params.scad의 검증 echo가 "!!" 경고를 내도 사람이 OpenSCAD 콘솔을
    열어야만 알 수 있었다(#61). 이제 `python tasks.py check`가 cad 작업으로 이
    경고를 잡는다.
    - cad 작업: OpenSCAD로 preview·print 두 모드를 `-o <모드>.echo`로 실행한다.
    exit 0이 아님, echo 0줄, "!!" 경고, WARNING·ERROR 줄 중 하나라도 있으면
    실패한다. OpenSCAD는 없는 변수·모듈을 경고만 하고 exit 0으로 끝나기 때문이다.
    - OpenSCAD가 없는 PC에서는 이유와 설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
2026-10-19 [kicad] 핀 좌표·배선 방향 수정과 실제 넷리스트 검증 (#217)
    * [kicad] 핀 좌표와 배선 방향을 고치고 실제 넷리스트를 검사
    * [kicad] 교차 리뷰 반영과 예상 밖 핀 회귀 검사
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2026-10-21 [cad] 발주용 STL 일괄 내보내기, 커플러 두 크기, 완성 모습 렌더 (#60)
    * [cad] 발주용 STL 일괄 내보내기, 커플러 두 크기, 완성 모습 렌더 추가
    cad/tools/export_print_parts.py가 발주 STL 10개를 만들고 부품마다 크기, 부피,
    열린 모서리를 검사한다. 9/18 STL의 vane_ring은 9/19 수정 전 형상이었다.
    혼 실측 전에 한 번에 발주하려고 vane_coupler에 슬롯 여유 인자를 넣고 +0.4 mm
    세트를 같이 뽑는다. cad/showcase.scad는 EDF, 전자부품, 배선을 더한 발표용
    장면이고, 서보선이 흡입구를 피해 가야 하며 연장선이 필요하다는 점을 README에 적었다.
    기본 preview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
2026-10-31 [sim] PD와 PPO를 복원시간·오버슈트·정상오차·넘어짐으로 비교한 표 (compare_metrics.py) (#280)
    * [sim] evaluate.py: 지표 계산을 episode_metrics()로 나누고 0 넘음 오버슈트를 더한다
    run_episodes()의 지표 계산을 에피소드 하나의 롤·피치 기록을 받는
    episode_metrics()로 옮겼다. 손으로 만든 기록으로 검사하려는 것이다.
    기존 키(overshoot, settle_s, steady_err_deg 등)의 정의는 바꾸지 않았다.
    PD 200 seed에서 옛 코드와 settle_s, settle_censored, mean_reward가 같고,
    overshoot와 steady_err_deg는 1e-9 수준만 다르다(float32 대신 float64로 hypot).
    새 키 overshoot_cross는 초기 기울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
2026-11-08 [sim] compare_metrics.py에 TC-3 기울기 10° 초기 조건 표를 더한다 (#310)
    * [sim] compare_metrics.py에 TC-3 기울기 10° 초기 조건 표를 더한다 (#276)
    마스터 설계 §11 TC-3은 ±10° 초기 오프셋인데 #266의 표는 학습 분포
    (세 축 각각 U(-0.3, 0.3) rad)만 썼다.
    - hopper_aviary.py: reset(options={"initial_tilt_deg": x})를 더했다.
    기울기 hypot(phi, theta)를 x°로 고정하고, 방향은 새 난수 흐름
    initial_tilt_dir에서 균등하게 뽑고, 요는 0으로 둔다. 옵션이 없으면
    초기 자세와 랜덤화 값이 main과 같다(seed 0-199 비교).
    모르는 키와 범위 밖 값은 ValueError를 낸다.
    - evaluate.py: r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
2026-11-08 [sim] 발표 비교표의 오버슈트를 0° 넘음 하나로 정하고 근거를 마스터 설계 §11.2에 적는다 (#320)
    * [sim] 비교표의 오버슈트를 0° 넘음 하나로 정한다
    #273 결정. 발표 비교표와 format_table()의 "오버슈트" 열은 0° 넘음
    (overshoot_cross)만 쓴다. 수평을 지나 반대쪽으로 기운 최대 각도를
    초기 기울기로 나눈 값이고 MATLAB stepinfo 정의(yfinal = 0)와 같다.
    - evaluate.py: 초기값 초과(예전 키 overshoot)를 뺐다. 키의 뜻을 바꾸지
    않으려고 overshoot_cross 이름은 그대로 둔다. format_table()은
    overshoot_cross를 %로 쓰고 정의 한 줄을 붙인다.
    - compare_metrics.py: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
2026-11-08 [sim] tasks.py train이 ppo_ablation.py로 crashcost 1M을 학습한다 (#348)
    train.py는 #230 전 설정(스로틀을 정책이 정함, 200k)이었다. 이 설정은 학습 seed 3개
    모두 스로틀 0 지름길로 갔다(ppo-ablation.md). 그래서 train.py를 지우고
    tasks.py train이 #230에서 가장 좋았던 조건(crashcost, 1M, 학습 seed 1)을
    ppo_ablation.py로 학습하게 했다. 학습 코드는 ppo_ablation.py 하나만 남는다.
    - train은 gate(PD 합격 기준)를 먼저 돌린다. train.py의 PD 확인을 옮겼다.
    - 결과는 git 제외 폴더 sim/runs/train/에 둔다. 저장소 모델과 runs/230/ 결과를 덮지 않는다.
    - check와 CI는 train을 돌리지 않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
2026-11-08 [sim] crashcost_mixer·crashcost_vecnorm 1M 결과를 ppo-ablation 표에 더한다 (#344) (#358)
    * [sim] crashcost_mixer 1M 학습 seed 0-2 결과를 더한다 (#344)
    #230에서 200k만 돌린 crashcost_mixer를 1M 스텝으로 학습했다.
    result.json, curve.csv, model.json만 넣는다. 모델 zip과 monitor.csv는 넣지 않는다(#230과 같다).
    * [sim] crashcost_vecnorm 1M 학습 seed 0-2 결과를 더한다 (#344)
    #230에서 200k만 돌린 crashcost_vecnorm을 1M 스텝으로 학습했다.
    result.json, curve.csv, model.json만 넣는다. model.zip, vecnormalize.pkl, monitor.csv는 넣지 않는다.
    * [docs] ppo-ablation.md 표에 2차 조합 1M 결과를 더한다 (#344)
    crashc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
2026-11-08 [sim] crashcost_mixer 1M 곡선이 400k 뒤 나빠지는 원인을 확인한다 (#359) (#360)
    * [sim] ppo_ablation.py에 SB3 학습 지표 기록과 보상 항 분해를 더한다 (#359)
    train --sb3-log: SB3 학습 지표를 sb3/progress.csv에, 정책을 50k마다
    checkpoints/에 남긴다. 난수를 쓰지 않아 학습 결과는 같다(4096 스텝에서
    policy.pth SHA-256이 --sb3-log 유무와 상관없이 같았다).
    breakdown: 모델 리턴을 보상 항(기울기, 요, 각속도, 행동 크기)으로 나누고
    행동이 [-1, 1] 경계에 붙는 비율을 잰다. crashcost_mixer 1M 곡선이
    나빠지는 원인을 찾는 데 쓴다.
    * [sim] crashcost_mixer 1M 곡선 하락의 원인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
2026-11-08 [sim] tasks.py train 시간 안내에 Windows 러너 측정값(약 18분)을 더한다 (#352) (#363)
    windows-latest 러너에서 python tasks.py train(crashcost 1M)이 1087 s 걸렸다.
    같은 CPU의 ubuntu-latest는 835 s였다. 서버 값(약 23분)과 함께 적고,
    부원 PC는 CPU가 달라서 시간이 다르다고 쓴다.
    ppo-ablation.md §재현에 세 장비의 시간과 result.json 비교 표를 더한다.
    실행 기록: https://github.com/COSMOS-Aero-Engineering/COSMOS-TVC-Hopper/actions/runs/42519282731
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2026-11-08 [sim] crashcost_mixer 1M 곡선 하락을 학습률 감쇠나 target_kl이 막는지 확인한다 (#367) (#368)
    * [sim] ppo_ablation.py train에 --lr-schedule, --target-kl 변형을 더한다 (#367)
    crashcost_mixer 1M 곡선 하락을 학습률 감쇠나 target_kl이 막는지 시험하려고 더했다.
    두 옵션이 기본값이면 PPO에 인자를 넘기지 않는다. 그래서 기존 조건의 학습은 그대로다.
    변형 결과는 runs/367/에 두고, json에 variant를 적는다. table은 variant로도 묶는다.
    * [sim] 학습률 감쇠와 target_kl 0.02의 crashcost_mixer 1M 결과를 적는다 (#367)
    학습 seed 0-2를 두 설정으로 1M씩 학습했다. 두 설정 모두 400k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
